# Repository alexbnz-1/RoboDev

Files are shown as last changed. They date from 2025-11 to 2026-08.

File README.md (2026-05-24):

# RoboDev

An open-source STM32-based robotics carrier board with integrated WiFi. Plug in power, plug in your motors and sensors — that's it. No breadboard, no stacked breakout boards, no wiring harness.

> **Status:** Schematic substantially complete · PCB layout not yet started

---

## Architecture

RoboDev uses a two-MCU design:

| | |
|---|---|
| **Primary MCU** | STM32G431RBTx · Cortex-M4F 170 MHz · motor control, real-time I/O |
| **WiFi co-processor** | ESP32-C3-MINI-1-N4 · SPI-connected · handles wireless comms |

---

## What's on the board

| | |
|---|---|
| **DC motors** | 4 channels · DRV8874PWPR · up to ~40 V · ~5 A cont. |
| **Servos** | 16 channels · PCA9685PW · 5 V servo rail |
| **Steppers** | 2× NEMA 17 · TMC2209-LA-T · StealthChop2 · silent operation |
| **CAN bus** | SN65HVD230D · ISO 11898-1 · screw terminal + 5.08 mm connector |
| **IMU** | BMI270 · 6-axis accel + gyro · SPI interface |
| **16-bit ADC** | ADS1115IDGST · 4-channel · I²C |
| **Native ADC** | 3× 2.54 mm headers · STM32 ADC |
| **GPIO expander** | PCF8574DW · 8 additional I/O · I²C |
| **Encoders** | 2 channels · 2.54 mm headers |
| **I²C expansion** | 16 independent ports · mix of QWIIC (JST SH) + 2.54 mm · 2× TCA9548APWR mux |
| **USB** | Type-C · USB4085-GF-A |
| **SWD debug** | 2.54 mm header |
| **UART** | 2× headers (debug + general) |
| **Power input** | XT60PW-M · reverse polarity protection · slide switch |

---

## Motor compatibility

| Motor | Works? | Notes |
|---|---|---|
| TT yellow gearmotors (2WD/4WD) | ✓ | Ideal fit |
| Pololu micro/mini gearmotors | ✓ | Well within limits |
| 25–37 mm DC gearmotors | ✓ | Software current limiting recommended near stall |
| Hobby servos | ✓ | Up to 16 channels via PCA9685 |
| NEMA 17 steppers | ✓ | TMC2209 · 2 A RMS / 2.8 A peak |
| CAN motor controllers (VESC, ODrive) | ✓ | Via SN65HVD230D CAN transceiver |
| 775-size / high-current motors | ✗ | Exceeds DRV8874 — use an external driver |

---

## Power

Five independent rails from a single XT60 input with reverse polarity protection (IRF4905 P-channel MOSFET) and a slide switch.

```
XT60  →  IRF4905 (reverse protect)  →  slide switch
           ├── VMOT    adj. buck (XL4016)  →  DC motors
           ├── VSTEP   adj. buck (XL4016)  →  steppers
           ├── +5V     LM2596T-5           →  servo rail + USB
           └── +3V3    AP2112K-3.3 LDO     →  STM32 + ESP32-C3 + all logic
```

VMOT and VSTEP are separate adjustable bucks so DC motors and steppers can run at different voltages simultaneously.

---

## I²C expansion

16 independent I²C ports behind two TCA9548APWR mux ICs — at zero GPIO cost, sharing the existing I²C bus. Each port is an isolated bus segment, so you can connect multiple devices with the same address across different ports without conflict.

3 ports are QWIIC (JST SH), the rest are standard 2.54 mm 4-pin headers. All carry GND / 3.3V / SDA / SCL.

---

## I²C address map

| Address | Device |
|---|---|
| 0x20 | PCF8574DW — digital GPIO expander |
| 0x3C | OLED display (user-supplied, optional) |
| 0x40 | PCA9685PW — 16-channel servo PWM |
| 0x48 | ADS1115IDGST — 16-bit ADC |
| 0x70 | TCA9548A Mux #1 — expansion ports 0–7 |
| 0x71 | TCA9548A Mux #2 — expansion ports 8–15 |

> BMI270 IMU is on SPI (via ESP32-C3), not I²C.

---

## Schematic structure

The KiCad project uses a hierarchical multi-sheet design:

| Sheet | Contents |
|---|---|
| Root | Top-level interconnect, mounting holes |
| `power` | XT60 input, reverse protect, all buck converters, LDO |
| `stm32` | STM32G431RBTx, SN65HVD230D CAN, USB-C, SWD, UART, ADC headers, encoders |
| `spi_bus` | ESP32-C3-MINI-1-N4 WiFi module, BMI270 IMU, 74HC595 shift register |
| `i2c_bus` | TCA9548A ×2 muxes, ADS1115 ADC, PCF8574 GPIO expander, all I²C headers |
| `motor_dc` | DRV8874PWPR ×4, motor output terminals, fault LEDs |
| `motor_stepper` | TMC2209-LA-T ×2, stepper output terminals, UART config |
| `motor_servo` | PCA9685PW, 16-channel servo headers |

---

## Project status

- [x] Design spec complete
- [x] KiCad schematic — substantially complete (all major blocks drawn)
- [ ] PCB layout
- [ ] Bringup firmware (I²C scan, PWM test, CAN loopback, UART echo)
- [ ] TCA9548A reverse-ARP HAL
- [ ] BMI270 driver + sensor fusion
- [ ] TMC2209 UART config
- [ ] Full LCSC/Mouser BOM with pricing

---

## Bill of materials

Key ICs: STM32G431RBTx · ESP32-C3-MINI-1-N4 · DRV8874PWPR ×4 · TMC2209-LA-T ×2 · PCA9685PW · ADS1115IDGST · PCF8574DW · TCA9548APWR ×2 · SN65HVD230D · BMI270 · USB4085-GF-A · XL4016 ×2 · LM2596T-5 · AP2112K-3.3

---

## Repo structure

```
/
├── hardware/
│   └── Robodev/     KiCad project (schematic + PCB)
├── firmware/        ESP-IDF / STM32 firmware (not yet started)
├── docs/
│   ├── Datasheets/  Component datasheets
│   └── RoboDevDesignSpec.docx
└── README.md
```

---

## Contributing

This is an early-stage open hardware project — no PCB has been fabricated yet. If you want to follow along or contribute, the most useful things right now are:

- KiCad schematic review
- Firmware: STM32 HAL bringup, TCA9548A I²C mux driver, TMC2209 UART configuration
- ESP32-C3 SPI bridge firmware
- BMI270 SPI driver + Madgwick/Mahony filter

---

*STM32 + ESP32-C3 Integrated Robotics Carrier Board · May 2026*

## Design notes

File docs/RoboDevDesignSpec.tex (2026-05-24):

% RoboDev Design Specification
% STM32G431 + ESP32-C3 Integrated Robotics Prototyping Board

\documentclass[11pt,a4paper]{article}

% ── Encoding & fonts ─────────────────────────────────────────────────────────
\usepackage[T1]{fontenc}
\usepackage[utf8]{inputenc}
\usepackage{lmodern}
\usepackage{microtype}

% ── Page layout ──────────────────────────────────────────────────────────────
\usepackage[a4paper, top=25mm, bottom=25mm, left=25mm, right=25mm]{geometry}

% ── Tables ───────────────────────────────────────────────────────────────────
\usepackage{booktabs}
\usepackage{array}
\usepackage{longtable}
\usepackage{tabularx}
\usepackage{multirow}

% ── Colour & graphics ────────────────────────────────────────────────────────
\usepackage[table]{xcolor}
\definecolor{newrow}{RGB}{214,234,248}   % light blue — new in v0.8
\definecolor{warnbg}{RGB}{255,243,205}  % amber — warning boxes
\definecolor{infobg}{RGB}{232,245,233}  % green — info boxes
\definecolor{headergray}{RGB}{52,73,94} % dark header
\definecolor{rowalt}{RGB}{242,242,242}  % alternating row grey

% ── Headings & lists ─────────────────────────────────────────────────────────
\usepackage{titlesec}
\usepackage{enumitem}
\setlist[itemize]{noitemsep, topsep=3pt}

% ── Hyperlinks ───────────────────────────────────────────────────────────────
\usepackage[colorlinks=true, linkcolor=blue!60!black, urlcolor=blue!60!black,
            pdftitle={RoboDev Design Specification v0.8},
            pdfauthor={RoboDev Project}]{hyperref}

% ── Header / footer ──────────────────────────────────────────────────────────
\usepackage{fancyhdr}
\pagestyle{fancy}
\fancyhf{}
\renewcommand{\headrulewidth}{0.4pt}
\fancyhead[L]{\small\textbf{RoboDev} — Design Specification}
\fancyhead[R]{\small v0.8 · May 2026}
\fancyfoot[C]{\small\thepage}

% ── Custom environments ───────────────────────────────────────────────────────
\usepackage{mdframed}
\newmdenv[backgroundcolor=warnbg, linecolor=orange!70!black,
          linewidth=0.8pt, innerleftmargin=8pt, innerrightmargin=8pt,
          innertopmargin=4pt, innerbottommargin=4pt]{warningbox}
\newmdenv[backgroundcolor=infobg, linecolor=green!60!black,
          linewidth=0.8pt, innerleftmargin=8pt, innerrightmargin=8pt,
          innertopmargin=4pt, innerbottommargin=4pt]{infobox}

% ── Misc ─────────────────────────────────────────────────────────────────────
\usepackage{parskip}
\usepackage{textcomp}
\usepackage{siunitx}
\usepackage{amsmath}
\usepackage{amssymb}    % $\checkmark$

% ─────────────────────────────────────────────────────────────────────────────

\begin{document}

% ── Title page ───────────────────────────────────────────────────────────────
\begin{titlepage}
  \centering
  \vspace*{2cm}
  {\Huge\bfseries RoboDev\par}
  \vspace{0.5cm}
  {\large STM32G431 + ESP32-C3 Integrated Robotics Prototyping Board\par}
  \vspace{0.3cm}
  {\normalsize Design Specification $\mid$ v0.8 $\mid$ May 2026\par}
  \vspace{2cm}
  \noindent\rule{\textwidth}{0.4pt}
  \vspace{0.5cm}

  \begin{tabular}{ll}
    \textbf{Status}  & Schematic substantially complete — PCB layout not yet started \\
    \textbf{MCU}     & STM32G431RBTx (primary) + ESP32-C3-MINI-1-N4 (WiFi co-processor) \\
    \textbf{Repo}    & \url{https://github.com/alexbnz-1/RoboDev} \\
  \end{tabular}
  \vspace{0.5cm}
  \noindent\rule{\textwidth}{0.4pt}
\end{titlepage}

% ── Table of contents ─────────────────────────────────────────────────────────
\tableofcontents
\clearpage

% ─────────────────────────────────────────────────────────────────────────────
\section*{Revision History}
\addcontentsline{toc}{section}{Revision History}

\rowcolors{2}{rowalt}{white}
\begin{longtable}{p{1.3cm} p{2cm} p{11cm}}
  \toprule
  \rowcolor{headergray}\color{white}\textbf{Version} &
  \color{white}\textbf{Date} &
  \color{white}\textbf{Summary of Changes} \\
  \midrule\endhead
  v0.1 & Mar 2026 & Initial document from notebook notes (22 Oct -- 17 Nov 2025). \\
  v0.2 & Mar 2026 & DRV8245-Q1 \textrightarrow{} DRV8874. MPU-6050 \textrightarrow{} BMI270. \\
  v0.3 & Mar 2026 & Soldered WROOM module \textrightarrow{} ESP32-S3 DevKitC-1 v1.1 in dual-row headers. \\
  v0.4 & Mar 2026 & NEMA\,17 stepper support: 2$\times$ TMC2209, GPIO26--31 allocated. \\
  v0.5 & Mar 2026 & MPU-6050 GY-521 replaces BMI270. ADS1115, PCF8574, OLED header. Servos 8\textrightarrow{}16. SPI/UART/carrier USB-C removed. 5$\times$ ADC1 headers. \\
  v0.6 & Mar 2026 & CAN bus (TWAI, GPIO7/32, SN65HVD230). Encoders 4\textrightarrow{}2. nFAULT\textrightarrow{}indicator LED. UART1 header (GPIO47/21). GPIO38/48 written off. Separate Vmot-DC and Vstep rails. 0 spare GPIOs. BOM \textasciitilde{}NZ\$82.81. \\
  v0.7 & Mar 2026 & \textbf{$\star$\ I$^2$C expansion array:} 2$\times$ TCA9548A mux (0x70/0x71) + 6$\times$ Qwiic JST\,SH + 10$\times$ 2.54\,mm 4-pin headers = 16 independent expansion ports. Reverse-ARP HAL for automatic peripheral discovery. BOM \textasciitilde{}NZ\$90--92. \\
  \rowcolor{newrow}
  v0.8 & May 2026 & \textbf{$\star$\ Dual-MCU architecture:} STM32G431RBTx replaces ESP32-S3 as primary MCU. ESP32-C3-MINI-1-N4 added as SPI-attached WiFi/BT co-processor. BMI270 IMU moves to SPI (co-processor sheet). USB4085-GF-A Type-C on carrier. SWD debug port added. XT60PW-M replaces XT30 power connector. IRF4905 PMOS reverse protection. 74HC595 shift register added. XL4016 $\times$2 for VMOT + VSTEP. KiCad schematic implementation begun (all major blocks drawn). \\
  \bottomrule
\end{longtable}

% ─────────────────────────────────────────────────────────────────────────────
\section{Introduction}

RoboDev is an open-source integrated robotics prototyping board built around a \textbf{dual-MCU architecture}: an STMicroelectronics STM32G431RBTx Cortex-M4F as the primary motor control processor, and an Espressif ESP32-C3-MINI-1-N4 module as a SPI-attached WiFi and Bluetooth co-processor. It is designed to eliminate the wiring overhead that typically accompanies microcontroller-based robotics projects by integrating motor drivers, a servo PWM controller, stepper motor drivers, a CAN bus transceiver, an IMU, analogue ADC expanders, digital GPIO expansion, an I$^2$C expansion array, and a complete multi-rail power supply onto a single carrier PCB.

The core philosophy of RoboDev is that only three types of wire should ever need to be connected to the board: power in, and wires out to sensors and actuators. All signal routing --- from the MCU to driver ICs, from the I$^2$C bus to peripherals, from the power switch to every rail --- is handled on the PCB itself.

\subsection{Motivation}

Robotics prototyping typically requires a breadboard or custom wiring harness to connect motor driver breakout boards, servo controllers, and sensor modules. This introduces noise susceptibility, mechanical fragility, and significant bring-up time before any firmware can be tested. RoboDev solves this by providing a production-ready carrier board with the STM32G431RBTx at the centre --- a Cortex-M4F processor from ST's G4 series that is purpose-built for motor control and digital power conversion, with hardware PWM timers, FDCAN, and a hardware FPU.

Wireless connectivity is provided by the ESP32-C3-MINI-1-N4, mounted on the carrier and connected to the STM32 via SPI. This separation of concerns keeps the hard-real-time motor control tasks on the deterministic STM32 while offloading WiFi, Bluetooth, and any cloud connectivity tasks to the ESP32-C3.

\subsection{Design Philosophy}

\begin{itemize}
  \item Full-featured and self-contained --- no daughterboards or breakout modules required
  \item Dual-MCU architecture: STM32G431RBTx for real-time control; ESP32-C3-MINI-1-N4 for wireless
  \item Any motor type supported simultaneously: 4$\times$ brushed DC, 16$\times$ servo, 2$\times$ NEMA\,17 stepper, and CAN-capable motor controllers
  \item BMI270 6-axis IMU on SPI for high-speed attitude estimation
  \item Three independently adjustable power rails for motors, steppers, and servos
  \item 16-port I$^2$C expansion array via 2$\times$ TCA9548A mux (zero GPIO cost)
  \item All components hand-solderable --- no BGA or ultra-fine-pitch packages
  \item Open source: schematics, PCB layout, firmware, and documentation on GitHub
\end{itemize}

\subsection{Target Applications}

\begin{itemize}
  \item 2WD and 4WD wheeled robot platforms
  \item Multi-axis robot arms with CAN-capable joint controllers
  \item Mechatronics rigs requiring mixed motor types on a single controller
  \item Autonomous vehicles with wireless telemetry and IMU sensor fusion
  \item Sensor-dense robots using the I$^2$C expansion array for multiple sensors
  \item Educational robotics platforms requiring a robust, well-documented base board
\end{itemize}

% ─────────────────────────────────────────────────────────────────────────────
\section{System Overview}

RoboDev uses a two-MCU design. The \textbf{STM32G431RBTx} is the primary processor, handling all real-time motor control, CAN communication, sensor interfacing, and I$^2$C bus management. The \textbf{ESP32-C3-MINI-1-N4} sits alongside it on the carrier PCB, connected to the STM32 via SPI, and handles all WiFi and Bluetooth tasks.

The board is divided into eight functional domains: power management, primary MCU (STM32), WiFi co-processor (ESP32-C3), motor control (DC, stepper, servo), communication (I$^2$C, CAN, UART), sensing (IMU, analogue, digital), expansion (Qwiic, GPIO headers), and the I$^2$C expansion array.

\subsection{Core Requirements Summary}

\rowcolors{2}{rowalt}{white}
\begin{longtable}{p{4.5cm} p{10cm}}
  \toprule
  \rowcolor{headergray}\color{white}\textbf{Category} & \color{white}\textbf{Requirement / Specification} \\
  \midrule\endhead
  Primary MCU & STM32G431RBTx $\cdot$ Cortex-M4F $\cdot$ 170\,MHz $\cdot$ FPU $\cdot$ 128\,KB Flash $\cdot$ LQFP-64 \\
  WiFi Co-processor & ESP32-C3-MINI-1-N4 $\cdot$ SPI-connected $\cdot$ 802.11b/g/n + Bluetooth 5 \\
  DC Motors & 4 channels $\cdot$ DRV8874PWPR $\cdot$ 4.5--37\,V $\cdot$ 2.1\,A cont.\,/ 6\,A peak $\cdot$ nFAULT LED \\
  Servos & 16 channels $\cdot$ PCA9685PW I$^2$C PWM driver (0x40) $\cdot$ 12-bit resolution $\cdot$ 5\,V servo rail \\
  Stepper Motors & 2 channels $\cdot$ TMC2209-LA-T $\cdot$ NEMA\,17 $\cdot$ 2\,A\,RMS / 2.8\,A peak $\cdot$ UART-configurable $\cdot$ StealthChop2 \\
  CAN Bus & FDCAN (ISO\,11898-1) $\cdot$ SN65HVD230D 3.3\,V transceiver $\cdot$ up to 1\,Mbps $\cdot$ 5.08\,mm screw terminal \\
  IMU & BMI270 $\cdot$ 6-axis accel + gyro $\cdot$ SPI interface $\cdot$ on co-processor sheet \\
  Quadrature Encoders & 2 channels $\cdot$ 4-pin 2.54\,mm headers \\
  Native Analogue ADC & 3$\times$ 2.54\,mm headers $\cdot$ STM32 ADC inputs \\
  I$^2$C Analogue ADC & 4 channels $\cdot$ ADS1115IDGST (0x48) $\cdot$ 16-bit $\cdot$ I$^2$C \\
  GPIO Expander & PCF8574DW (0x20) $\cdot$ 8-channel digital I/O $\cdot$ I$^2$C \\
  I$^2$C Expansion Array & 16 independent ports $\cdot$ 2$\times$ TCA9548APWR mux (0x70/0x71) $\cdot$ 3$\times$ Qwiic + 13$\times$ 2.54\,mm $\cdot$ zero GPIO cost \\
  USB & Type-C $\cdot$ USB4085-GF-A $\cdot$ on STM32 sheet \\
  SWD Debug & 2.54\,mm header $\cdot$ STM32 programming and debug \\
  UART Headers & 2$\times$ 2.54\,mm (debug + general purpose) \\
  Shift Register & 74HC595 $\cdot$ 8-bit serial-in parallel-out $\cdot$ SPI-driven (ESP32-C3 sheet) \\
  Power Input & XT60PW-M $\cdot$ reverse polarity protection (IRF4905 PMOS) $\cdot$ slide switch \\
  \bottomrule
\end{longtable}

% ─────────────────────────────────────────────────────────────────────────────
\section{Power Architecture}

The power system is designed around four independent rails, each serving a distinct subsystem. Separating VMOT from VSTEP allows brushed DC motors and stepper motors to be run at different voltages simultaneously. All rails are derived from a single protected XT60 input, switched by a common high-current slide switch.

\subsection{Power Input and Protection}

Power enters the board via an XT60PW-M connector. Input voltage should be at least 6\,V to allow headroom for the buck converter generating the 5\,V logic rail. Do not exceed 36\,V (the rated ceiling of the XL4016 buck converters).

An IRF4905 P-channel power MOSFET provides reverse voltage protection on VIN before the power switch. MBR2045CT Schottky diodes are used for power path management. An SS14 diode handles USB/power path arbitration.

\begin{warningbox}
\textbf{Warning:} A high-current slide switch (OS102011MS2QN1) is placed after the reverse voltage protection circuit. It switches all rails simultaneously. When laying out the PCB, ensure the switch trace width is adequate for the total system current.
\end{warningbox}

\subsection{Power Rails}

\rowcolors{2}{rowalt}{white}
\begin{longtable}{p{2cm} p{2.5cm} p{2.2cm} p{3cm} p{4.8cm}}
  \toprule
  \rowcolor{headergray}\color{white}\textbf{Rail} &
  \color{white}\textbf{Output} &
  \color{white}\textbf{Current} &
  \color{white}\textbf{Load} &
  \color{white}\textbf{Key Component / Notes} \\
  \midrule\endhead
  VMOT   & Adj. 4.5--24\,V & 5\,A+ cont. & DC Motors M1--M4     & XL4016 step-down $\cdot$ trimmer pot on FB $\cdot$ 470\,\textmu F bulk $\times$4 \\
  VSTEP  & Adj. 4.5--24\,V & 3\,A+ cont. & Steppers S1--S2      & XL4016 step-down $\cdot$ independent rail \\
  +5\,V  & Fixed 5\,V      & 3\,A+ cont. & Servo rail, USB, ESP32-C3 & LM2596T-5 synchronous buck $\cdot$ 33\,\textmu H inductor \\
  +3.3\,V& Fixed 3.3\,V    & 1\,A+ cont. & STM32, all ICs, sensors & AP2112K-3.3 LDO from 5\,V $\cdot$ all I$^2$C devices \\
  \bottomrule
\end{longtable}

\begin{warningbox}
\textbf{Warning:} VMOT and VSTEP are independent adjustable XL4016 buck converters. Each has its own trimmer potentiometer. Label both clearly on the PCB silkscreen to prevent accidental cross-connection.
\end{warningbox}

\subsection{Bulk Decoupling Capacitors}

Each DRV8874 DC motor driver requires at least one electrolytic bulk capacitor rated for the VMOT voltage placed as close as possible to the VM pin. A minimum of 470\,\textmu F at 50\,V is specified per driver. Each TMC2209 stepper driver similarly requires bulk capacitance on the VSTEP rail. All ICs additionally receive 100\,nF ceramic decoupling capacitors.

% ─────────────────────────────────────────────────────────────────────────────
\section{Microcontrollers}

\subsection{Primary MCU --- STM32G431RBTx}

The STM32G431RBTx (U\_MCU1) is a 64-pin LQFP Cortex-M4F microcontroller from STMicroelectronics' G4 series. Running at 170\,MHz with a hardware FPU, it is purpose-built for motor control and digital power conversion applications.

\begin{warningbox}
\textbf{Note:} The schematic sheet is labelled \texttt{stm32} and uses file \texttt{esp32.kicad\_sch} — a legacy filename from the earlier ESP32-S3 design. The actual placed component is STM32G431RBTx.
\end{warningbox}

Key peripherals used on this board:

\begin{itemize}
  \item \textbf{Timers (TIM/HRTIM)} --- motor PWM generation for M1--M4 DC motor channels and S1--S2 stepper STEP pulses
  \item \textbf{FDCAN} --- hardware CAN controller via SN65HVD230D transceiver
  \item \textbf{I$^2$C} --- shared bus for PCA9685, ADS1115, PCF8574, TCA9548A $\times$2
  \item \textbf{SPI} --- connection to ESP32-C3-MINI-1-N4 co-processor and 74HC595 shift register
  \item \textbf{UART/USART} --- TMC2209 UART configuration interface + debug/general UART headers
  \item \textbf{ADC} --- native ADC inputs broken out to 3$\times$ 2.54\,mm headers
  \item \textbf{USB FS} --- via USB4085-GF-A Type-C connector
  \item \textbf{SWD} --- programming and debug via 2.54\,mm header (J\_SWD1)
\end{itemize}

The BOOT0 pin is pulled to GND via a 10\,k$\Omega$ resistor with a MJTP1230 push-button to allow entry into the DFU bootloader. A separate MJTP1230 provides system RESET. A 100\,nF capacitor is placed on the $\overline{\text{NRST}}$ pin.

\subsection{WiFi Co-processor --- ESP32-C3-MINI-1-N4}

The ESP32-C3-MINI-1-N4 (on the \texttt{spi\_bus} sheet) provides 802.11b/g/n WiFi and Bluetooth 5 LE connectivity. It is connected to the STM32 via SPI, with the following interface signals:

\begin{itemize}
  \item \textbf{SPI\_SCK, SPI\_MOSI, SPI\_MISO} --- SPI bus to/from STM32
  \item \textbf{SPI\_CS} --- chip select from STM32
  \item \textbf{SPI\_LATCH} --- latch signal (also drives 74HC595 shift register)
  \item \textbf{WIFI\_IRQ} --- interrupt output from ESP32-C3 to STM32
\end{itemize}

The ESP32-C3 also connects to the BMI270 IMU and the 74HC595 shift register on its sheet.

\subsection{74HC595 Shift Register}

A 74HC595 8-bit serial-in parallel-out shift register is placed on the \texttt{spi\_bus} sheet alongside the ESP32-C3. It is clocked via the SPI bus (or the SPI\_LATCH signal), providing 8 additional digital output lines without consuming extra GPIO on the STM32. Typical use cases include status LEDs, output expansion, and simple digital control signals.

% ─────────────────────────────────────────────────────────────────────────────
\section{Signal Interface Summary}

The following table lists the hierarchical sheet pin names that cross between sheets in the KiCad schematic. Exact STM32 pin numbers are TBD (to be verified during PCB layout).

\rowcolors{2}{rowalt}{white}
\begin{longtable}{p{3.5cm} p{2cm} p{3cm} p{6cm}}
  \toprule
  \rowcolor{headergray}\color{white}\textbf{Signal} &
  \color{white}\textbf{Dir.} &
  \color{white}\textbf{Sheet} &
  \color{white}\textbf{Function} \\
  \midrule\endhead
  M1\_PWM / M1\_DIR & Out & stm32 \textrightarrow{} motor\_dc & DC motor M1 PWM + direction \\
  M2\_PWM / M2\_DIR & Out & stm32 \textrightarrow{} motor\_dc & DC motor M2 PWM + direction \\
  M3\_PWM / M3\_DIR & Out & stm32 \textrightarrow{} motor\_dc & DC motor M3 PWM + direction \\
  M4\_PWM / M4\_DIR & Out & stm32 \textrightarrow{} motor\_dc & DC motor M4 PWM + direction \\
  S1\_STEP/DIR/EN   & Out & stm32 \textrightarrow{} motor\_stepper & Stepper S1 control \\
  S2\_STEP/DIR/EN   & Out & stm32 \textrightarrow{} motor\_stepper & Stepper S2 control \\
  TMC\_UART\_TX/RX  & Bidir & stm32 $\leftrightarrow$ motor\_stepper & TMC2209 UART config bus \\
  I2C\_SCL/SDA      & Out & stm32 \textrightarrow{} i2c\_bus, motor\_servo & Shared I$^2$C bus \\
  SPI\_CS/MOSI/MISO/SCK & Bidir & stm32 $\leftrightarrow$ spi\_bus & SPI to ESP32-C3 + 74HC595 \\
  SPI\_LATCH        & Out & stm32 \textrightarrow{} spi\_bus & 74HC595 latch \\
  WIFI\_IRQ         & In  & spi\_bus \textrightarrow{} stm32 & ESP32-C3 interrupt \\
  IMU\_INT1         & In  & spi\_bus \textrightarrow{} stm32 & BMI270 interrupt \\
  GPIO\_INT         & In  & i2c\_bus \textrightarrow{} stm32 & PCF8574 interrupt \\
  IPROPI\_M1--M4    & In  & motor\_dc \textrightarrow{} i2c\_bus & DRV8874 current sense to ADS1115 \\
  VMOT              & Pwr & power \textrightarrow{} motor\_dc & DC motor power rail \\
  VSTEP             & Pwr & power \textrightarrow{} motor\_stepper & Stepper power rail \\
  VSERVO            & Pwr & power \textrightarrow{} motor\_servo & Servo power rail \\
  VBUS / ADC\_VIN   & Pwr & power \textrightarrow{} stm32 & USB bus power + ADC reference \\
  \bottomrule
\end{longtable}

% ─────────────────────────────────────────────────────────────────────────────
\section{Motor Control}

\subsection{DC Brushed Motors --- DRV8874PWPR \texorpdfstring{$\times$}{x} 4}

Four DRV8874PWPR H-bridge motor driver ICs (U\_M1--U\_M4) provide control for four independent brushed DC motor channels (M1--M4). The DRV8874 is a fully integrated H-bridge with hardware overcurrent protection, thermal shutdown, and undervoltage lockout.

\rowcolors{2}{rowalt}{white}
\begin{longtable}{p{5cm} p{10cm}}
  \toprule
  \rowcolor{headergray}\color{white}\textbf{Parameter} & \color{white}\textbf{Value / Detail} \\
  \midrule\endhead
  Part number & DRV8874PWPR (HTSSOP-16) \\
  Supply voltage (VM) & 4.5\,V -- 37\,V (VMOT rail) \\
  Continuous current & 2.1\,A per channel \\
  Peak current & 6\,A per channel \\
  Control M1 & M1\_PWM (PWM/Phase), M1\_DIR (DIR/Enable) from STM32 \\
  Control M2 & M2\_PWM, M2\_DIR \\
  Control M3 & M3\_PWM, M3\_DIR \\
  Control M4 & M4\_PWM, M4\_DIR \\
  Output connector & 2-pin 5.08\,mm screw terminal per channel \\
  nFAULT handling & All 4 nFAULT pins wired-OR open-drain \textrightarrow{} red indicator LED (LTST-C190KRKT). No MCU GPIO consumed. \\
  Bulk capacitance & 470\,\textmu F 50\,V electrolytic per driver (C\_VM1--C\_VM4), close to VM pin \\
  Current sense & IPROPI output routed to ADS1115 (A6--A9) for per-motor current monitoring \\
  \bottomrule
\end{longtable}

\subsection{NEMA 17 Stepper Motors --- TMC2209-LA-T \texorpdfstring{$\times$}{x} 2}

Two TMC2209-LA-T silent stepper motor driver ICs (U\_S1--U\_S2) drive two NEMA\,17 bipolar stepper motors from the independent VSTEP rail. The TMC2209 features StealthChop2 for near-silent operation and SpreadCycle for high-torque applications, configurable via UART.

\rowcolors{2}{rowalt}{white}
\begin{longtable}{p{5cm} p{10cm}}
  \toprule
  \rowcolor{headergray}\color{white}\textbf{Parameter} & \color{white}\textbf{Value / Detail} \\
  \midrule\endhead
  Part number & TMC2209-LA-T (QFN-28) \\
  Supply voltage (VM) & 4.5\,V -- 36\,V (VSTEP rail --- independent from VMOT) \\
  RMS current & 2.0\,A RMS per channel \\
  Peak current & 2.8\,A peak per channel \\
  Control S1 & S1\_STEP, S1\_DIR, S1\_EN (active LOW) \\
  Control S2 & S2\_STEP, S2\_DIR, S2\_EN (active LOW) \\
  EN pull-up & 10\,k$\Omega$ to 3.3\,V --- drivers disabled by default at power-on \\
  UART config & TMC\_UART\_TX/RX to STM32 (optional per-application current tuning) \\
  Bulk capacitance & 100\,\textmu F 35\,V+ per driver \\
  \bottomrule
\end{longtable}

\begin{infobox}
\textbf{Note:} The VSTEP rail is intentionally separate from VMOT. This allows, for example, 12\,V NEMA\,17 operation alongside 6\,V DC gearmotors simultaneously.
\end{infobox}

\subsection{Servo Motors --- PCA9685PW \texorpdfstring{$\times$}{x} 16}

A PCA9685PW 16-channel 12-bit PWM driver IC provides servo control for up to 16 hobby servo channels simultaneously via I$^2$C. All 16 PWM outputs are broken out to 3-pin 2.54\,mm servo headers carrying GND, VSERVO, and PWM signal.

\rowcolors{2}{rowalt}{white}
\begin{longtable}{p{5cm} p{10cm}}
  \toprule
  \rowcolor{headergray}\color{white}\textbf{Parameter} & \color{white}\textbf{Value / Detail} \\
  \midrule\endhead
  Part number & PCA9685PW (TSSOP-28) \\
  I$^2$C address & 0x40 (ADDR pins \textrightarrow{} GND) \\
  PWM resolution & 12-bit (4096 steps) \\
  PWM frequency & Configurable 24\,Hz -- 1526\,Hz (typically 50\,Hz for standard servos) \\
  Servo voltage & VSERVO (derived from +5\,V rail via MBR2045CT protection diode) \\
  Servo headers & 3-pin 2.54\,mm GND / VSERVO / PWM (16 channels) \\
  Control interface & I$^2$C via STM32 I$^2$C bus \\
  \bottomrule
\end{longtable}

\subsection{Motor Compatibility}

\rowcolors{2}{rowalt}{white}
\begin{longtable}{p{6cm} p{2cm} p{7cm}}
  \toprule
  \rowcolor{headergray}\color{white}\textbf{Motor Type} &
  \color{white}\textbf{Compatible?} &
  \color{white}\textbf{Notes} \\
  \midrule\endhead
  TT yellow gearmotors (2WD/4WD) & $\checkmark$ & Common chassis motors --- ideal fit \\
  Pololu micro/mini DC gearmotors & $\checkmark$ & Well within DRV8874 2.1\,A continuous rating \\
  25\,mm / 37\,mm DC gearmotors   & $\checkmark$* & Stall may approach 6\,A peak --- current limiting recommended \\
  775-size DC motors               & $\times$  & Exceeds DRV8874 continuous rating --- use external driver \\
  Hobby servos (3--8.4\,V)         & $\checkmark$ & PCA9685 servo rail, up to 16 channels simultaneously \\
  NEMA\,17 stepper motors          & $\checkmark$ & TMC2209 StealthChop2 $\cdot$ up to 2\,A RMS / 2.8\,A peak \\
  CAN motor controllers (VESC, ODrive) & $\checkmark$ & FDCAN via SN65HVD230D $\cdot$ ISO\,11898-1 \\
  \bottomrule
\end{longtable}

% ─────────────────────────────────────────────────────────────────────────────
\section{Communication Interfaces}

\subsection{\texorpdfstring{I$^2$C}{I2C} Bus}

A single I$^2$C bus from the STM32 carries all on-board I$^2$C peripherals plus the TCA9548A expansion array. Pull-up resistors of 4.7\,k$\Omega$ to 3.3\,V are provided on-board.

\rowcolors{2}{rowalt}{white}
\begin{longtable}{p{3cm} p{1.5cm} p{4cm} p{6cm}}
  \toprule
  \rowcolor{headergray}\color{white}\textbf{Device} &
  \color{white}\textbf{Addr.} &
  \color{white}\textbf{Function} &
  \color{white}\textbf{Notes} \\
  \midrule\endhead
  PCA9685PW         & 0x40 & 16-ch servo PWM driver   & Main bus --- always visible \\
  ADS1115IDGST      & 0x48 & 4-ch 16-bit ADC          & Main bus --- ADDR\textrightarrow{}GND \\
  PCF8574DW         & 0x20 & 8-ch digital GPIO expander & Main bus --- INT to STM32 (GPIO\_INT) \\
  OLED display      & 0x3C & 0.96\,'' display (user-supplied) & 4-pin 2.54\,mm header (J\_OLED1) \\
  TCA9548APWR Mux\,\#1 & 0x70 & I$^2$C mux --- ports 0--7 & Main bus --- always visible \\
  TCA9548APWR Mux\,\#2 & 0x71 & I$^2$C mux --- ports 8--15 & Main bus --- always visible \\
  Expansion 0--15   & Any  & User I$^2$C devices       & Behind mux --- no address conflicts \\
  \bottomrule
\end{longtable}

\begin{infobox}
\textbf{Note:} The BMI270 IMU is on \textbf{SPI}, not I$^2$C. It is located on the \texttt{spi\_bus} sheet alongside the ESP32-C3. The main I$^2$C bus has seven on-board devices; no address conflicts exist between them.
\end{infobox}

\subsection{CAN Bus (FDCAN)}

CAN bus support is implemented using the STM32G431's built-in FDCAN controller, conforming to ISO\,11898-1. An SN65HVD230D 3.3\,V CAN transceiver provides the physical layer.

\rowcolors{2}{rowalt}{white}
\begin{longtable}{p{4cm} p{11cm}}
  \toprule
  \rowcolor{headergray}\color{white}\textbf{Parameter} & \color{white}\textbf{Value / Detail} \\
  \midrule\endhead
  Protocol & ISO\,11898-1 (CAN 2.0A/B / CAN FD capable) via STM32 FDCAN hardware \\
  Transceiver & SN65HVD230D (SOIC-8, 3.3\,V compatible, up to 1\,Mbps) \\
  Bus connector & 5.08\,mm 2-pin screw terminal (J\_CAN1) --- CANH / CANL \\
  Termination & 120\,$\Omega$ resistor (R\_CAN\_TERM1) on board \\
  Logic level & 3.3\,V --- directly compatible with STM32G431 GPIO \\
  Use cases & CAN motor controllers (VESC, ODrive), robot arm joints, inter-board comms \\
  \bottomrule
\end{longtable}

\begin{warningbox}
\textbf{Warning:} Do not substitute the SN65HVD230D with a 5\,V transceiver such as the MCP2551. The STM32G431 GPIO pins are 3.3\,V tolerant; a 5\,V transceiver output will permanently damage the MCU.
\end{warningbox}

\subsection{USB (Type-C)}

A USB4085-GF-A USB Type-C connector (X1) on the STM32 sheet provides USB Full-Speed connectivity directly to the STM32G431's USB FS peripheral. This is used for firmware programming (DFU bootloader via BOOT0 button) and virtual COM port (VCP) communication.

\subsection{SWD Debug Interface}

A 4-pin 2.54\,mm SWD header (J\_SWD1) exposes the STM32G431's Serial Wire Debug interface (SWDIO / SWDCLK / GND / 3.3\,V). This supports programming and live debugging via ST-LINK, J-Link, or compatible probe.

\subsection{UART Headers}

\begin{itemize}
  \item \textbf{J\_UART\_DBG1} --- UART debug port (4-pin 2.54\,mm). Intended for serial monitor and low-level firmware diagnostics.
  \item \textbf{J\_UART2} --- General-purpose UART header (4-pin 2.54\,mm). Use for GPS (NMEA), LiDAR (RPLIDAR, TF-Luna), or any UART-based peripheral.
\end{itemize}

% ─────────────────────────────────────────────────────────────────────────────
\section{Sensing and Analogue Inputs}

\subsection{Inertial Measurement Unit --- BMI270}

The BMI270 6-axis IMU is placed on the \texttt{spi\_bus} sheet alongside the ESP32-C3-MINI-1-N4. It provides 3-axis accelerometer and 3-axis gyroscope data via SPI. An interrupt output (IMU\_INT1) is routed to the STM32 for data-ready notification.

\begin{itemize}
  \item Interface: SPI
  \item Interrupt: IMU\_INT1 \textrightarrow{} STM32
  \item Firmware: BMI270 SPI driver recommended; Madgwick or Mahony filter for attitude estimation
\end{itemize}

\subsection{Native Analogue Inputs --- ADC Headers}

Three 2.54\,mm headers (J\_ADC1, J\_ADC2, J\_ADC3) break out STM32G431 ADC input channels. Exact GPIO assignments are to be determined during schematic finalisation and PCB layout.

\begin{itemize}
  \item Pinout: GND / 3.3\,V / SIG (3-pin headers)
  \item Resolution: 12-bit (STM32 ADC1/ADC2)
\end{itemize}

\subsection{\texorpdfstring{I$^2$C}{I2C} Analogue Inputs --- ADS1115IDGST}

The ADS1115IDGST 16-bit I$^2$C ADC (U\_ADC1) provides four additional analogue channels (A6--A9) at significantly higher resolution than the native ADC. The DRV8874 IPROPI current sense outputs are routed here for per-motor current monitoring.

\begin{itemize}
  \item I$^2$C address: 0x48 (ADDR\textrightarrow{}GND)
  \item Resolution: 16-bit ($\pm$32767 counts), programmable gain: $\pm$0.256\,V to $\pm$6.144\,V FSR
  \item IPROPI inputs: IPROPI\_M1--M4 from DRV8874 \textrightarrow{} ADS1115 (via i2c\_bus sheet)
\end{itemize}

\subsection{PCF8574DW --- Digital GPIO Expander}

The PCF8574DW (U\_GPIO1) provides 8 additional digital I/O lines via I$^2$C at address 0x20. An INT signal is routed to the STM32 (GPIO\_INT) for interrupt-driven pin change notification. A pull-up resistor (R\_GPIO\_INT1) is placed on the INT line.

\subsection{Quadrature Encoders}

Two quadrature encoder channels are supported. Each channel provides a 4-pin 2.54\,mm header (J\_ENC1, J\_ENC2) with pinout GND / 3.3\,V / Chan-A / Chan-B.

\subsection{GPIO Header}

A general-purpose GPIO header (J\_GPIO1) breaks out additional STM32 GPIO pins for user-defined digital I/O.

% ─────────────────────────────────────────────────────────────────────────────
\section{\texorpdfstring{I$^2$C}{I2C} Expansion Array}

Two TCA9548APWR 8-channel I$^2$C multiplexers (U\_MUX1 at 0x70, U\_MUX2 at 0x71) are added to the main I$^2$C bus. Each provides 8 independently switched downstream channels, giving 16 expansion ports total. Each port is a fully isolated I$^2$C segment --- devices on different ports can share the same I$^2$C address without conflict.

\subsection{Expansion Port Layout}

\rowcolors{2}{rowalt}{white}
\begin{longtable}{p{1.2cm} p{3.5cm} p{3.5cm} p{2.5cm} p{4cm}}
  \toprule
  \rowcolor{headergray}\color{white}\textbf{Port} &
  \color{white}\textbf{Connector} &
  \color{white}\textbf{Mux Channel} &
  \color{white}\textbf{Isolation} &
  \color{white}\textbf{Notes} \\
  \midrule\endhead
  0  & QWIIC JST\,SH 4-pin & TCA9548A \#1 Ch0 & Independent & QWIIC port 1 on Mux\,\#1 \\
  1  & QWIIC JST\,SH 4-pin & TCA9548A \#1 Ch1 & Independent & QWIIC port 2 on Mux\,\#1 \\
  2  & QWIIC JST\,SH 4-pin & TCA9548A \#1 Ch2 & Independent & QWIIC port 3 on Mux\,\#1 \\
  3  & 2.54\,mm 4-pin      & TCA9548A \#1 Ch3 & Independent & GND/3.3\,V/SDA/SCL \\
  4  & 2.54\,mm 4-pin      & TCA9548A \#1 Ch4 & Independent & \\
  5  & 2.54\,mm 4-pin      & TCA9548A \#1 Ch5 & Independent & \\
  6  & 2.54\,mm 4-pin      & TCA9548A \#1 Ch6 & Independent & \\
  7  & 2.54\,mm 4-pin      & TCA9548A \#1 Ch7 & Independent & \\
  8  & QWIIC JST\,SH 4-pin & TCA9548A \#2 Ch0 & Independent & QWIIC port 1 on Mux\,\#2 \\
  9  & 2.54\,mm 4-pin      & TCA9548A \#2 Ch1 & Independent & \\
  10 & 2.54\,mm 4-pin      & TCA9548A \#2 Ch2 & Independent & \\
  11 & 2.54\,mm 4-pin      & TCA9548A \#2 Ch3 & Independent & \\
  12 & 2.54\,mm 4-pin      & TCA9548A \#2 Ch4 & Independent & \\
  13 & 2.54\,mm 4-pin      & TCA9548A \#2 Ch5 & Independent & \\
  14 & 2.54\,mm 4-pin      & TCA9548A \#2 Ch6 & Independent & \\
  15 & 2.54\,mm 4-pin      & TCA9548A \#2 Ch7 & Independent & \\
  \bottomrule
\end{longtable}

\subsection{TCA9548A Architecture}

\rowcolors{2}{rowalt}{white}
\begin{longtable}{p{5cm} p{10cm}}
  \toprule
  \rowcolor{headergray}\color{white}\textbf{Parameter} & \color{white}\textbf{Value / Detail} \\
  \midrule\endhead
  Part number & TCA9548APWR (TSSOP-24) \\
  I$^2$C address Mux\,\#1 & 0x70 (A2/A1/A0 = 0/0/0 \textrightarrow{} GND) \\
  I$^2$C address Mux\,\#2 & 0x71 (A2/A1/A0 = 0/0/1 \textrightarrow{} Mux\,\#2 A0 \textrightarrow{} 3.3\,V) \\
  Channels per IC & 8 independent I$^2$C downstream channels \\
  Total expansion ports & 16 (8 from Mux\,\#1 + 8 from Mux\,\#2) \\
  Supply voltage & 3.3\,V \\
  Pull-up resistors & 4.7\,k$\Omega$ on SDA/SCL of main bus only (mux outputs are active) \\
  Address conflict risk & None between ports --- each port is on an independently switched segment \\
  Reset pull-ups & 10\,k$\Omega$ pull-ups on /RESET pins of both TCA9548A ICs \\
  \bottomrule
\end{longtable}

\subsection{Reverse-ARP HAL --- Automatic Peripheral Discovery}

The firmware HAL implements a reverse-ARP discovery mechanism for the expansion array. On startup, the HAL iterates through all 16 expansion ports, temporarily enables each channel, performs an I$^2$C scan, records any device addresses found, and then disables the channel. The result is a port map that application code can query.

\begin{itemize}
  \item On startup: scan all 16 ports \textrightarrow{} build port map \textrightarrow{} log device addresses per port
  \item At runtime: request \texttt{i2c\_port\_N} \textrightarrow{} HAL enables TCA9548A channel \textrightarrow{} performs transaction \textrightarrow{} disables channel
  \item No address conflicts possible --- HAL enforces single-channel activation
\end{itemize}

\begin{warningbox}
\textbf{Warning:} Only one TCA9548A channel should be active at any time. The HAL enforces this. Do not manually write to the TCA9548A channel registers from application code while the HAL is active.
\end{warningbox}

% ─────────────────────────────────────────────────────────────────────────────
\section{Connector Reference}

\rowcolors{2}{rowalt}{white}
\begin{longtable}{p{3cm} p{2.5cm} p{1.5cm} p{2.5cm} p{5cm}}
  \toprule
  \rowcolor{headergray}\color{white}\textbf{Ref} &
  \color{white}\textbf{Type} &
  \color{white}\textbf{Qty} &
  \color{white}\textbf{Pitch} &
  \color{white}\textbf{Function / Pinout} \\
  \midrule\endhead
  J\_XT60             & XT60PW-M      & 1  & XT60       & VIN power input \\
  J\_CAN1             & Screw terminal& 1  & 5.08\,mm 2-pin & CAN: CANH / CANL \\
  J\_ENC1, J\_ENC2    & Pin header    & 2  & 2.54\,mm 4-pin & Encoders: GND / 3.3\,V / Chan-A / Chan-B \\
  J\_UART\_DBG1       & Pin header    & 1  & 2.54\,mm 4-pin & UART debug: GND / 3.3\,V / TX / RX \\
  J\_UART2            & Pin header    & 1  & 2.54\,mm 4-pin & UART general: GND / 3.3\,V / TX / RX \\
  J\_OLED1            & Pin header    & 1  & 2.54\,mm 4-pin & OLED: GND / 3.3\,V / SDA / SCL \\
  J\_SWD1             & Pin header    & 1  & 2.54\,mm 4-pin & SWD: GND / 3.3\,V / SWDIO / SWDCLK \\
  J\_ADC1--J\_ADC3    & Pin header    & 3  & 2.54\,mm 3-pin & ADC: GND / 3.3\,V / SIG \\
  J\_GPIO1            & Pin header    & 1  & 2.54\,mm 4-pin & Direct GPIO header \\
  Servo headers       & Pin header    & 16 & 2.54\,mm 3-pin & Servo: GND / VSERVO / PWM \\
  Motor terminals     & Screw terminal& 4  & 5.08\,mm 2-pin & DC motor outputs M1--M4 \\
  Stepper headers     & Pin header    & 2  & 2.54\,mm 4-pin & STEP/DIR/EN per stepper \\
  J\_MUX1\_CH0--CH7  & Mixed         & 8  & QWIIC / 2.54\,mm & I$^2$C expansion ports 0--7 \\
  J\_MUX2\_CH0--CH7  & Mixed         & 8  & QWIIC / 2.54\,mm & I$^2$C expansion ports 8--15 \\
  X1                  & USB Type-C    & 1  & USB4085-GF-A & USB FS / DFU programming \\
  H1--H4              & Mounting hole & 4  & M3 pad       & Grounded M3 mounting holes \\
  \bottomrule
\end{longtable}

% ─────────────────────────────────────────────────────────────────────────────
\section{Bill of Materials (v0.8)}

Estimated mid-range unit pricing at Qty\,=\,1. Excludes PCB assembly labour, shipping, and import duties. Rows highlighted in blue are new or significantly changed in v0.8.

\rowcolors{2}{rowalt}{white}
\begin{longtable}{p{0.5cm} p{4.5cm} p{3.5cm} p{0.8cm} p{5.5cm}}
  \toprule
  \rowcolor{headergray}\color{white}\textbf{\#} &
  \color{white}\textbf{Component} &
  \color{white}\textbf{Part Number} &
  \color{white}\textbf{Qty} &
  \color{white}\textbf{Notes} \\
  \midrule\endhead
  \rowcolor{newrow}1 & STM32G431RBTx MCU & STM32G431RBTx (LQFP-64) & 1 & Primary MCU, 170\,MHz Cortex-M4F \\
  \rowcolor{newrow}2 & ESP32-C3-MINI-1-N4 & ESP32-C3-MINI-1-N4 & 1 & WiFi/BT co-processor, SPI interface \\
  3 & DRV8874 H-Bridge & DRV8874PWPR (HTSSOP-16) & 4 & DC motors M1--M4 \\
  4 & SN65HVD230 CAN & SN65HVD230D (SOIC-8) & 1 & CAN bus transceiver \\
  5 & CAN screw terminal & 5.08\,mm 2-pin & 1 & CANH / CANL \\
  6 & nFAULT LED & LTST-C190KRKT Red & 1 & DRV8874 fault indicator \\
  7 & PCA9685 servo driver & PCA9685PW (TSSOP-28) & 1 & 16-ch PWM servo \\
  8 & ADS1115 ADC & ADS1115IDGST (MSOP-10) & 1 & 16-bit I$^2$C ADC, motor current sense \\
  9 & PCF8574 GPIO expander & PCF8574DW (SOIC-16) & 1 & 8-ch digital I/O expander \\
  10 & TCA9548A I$^2$C Mux & TCA9548APWR (TSSOP-24) & 2 & Mux\,\#1 (0x70), Mux\,\#2 (0x71) \\
  11 & QWIIC header & JST\,SH SM04B-SRSS-TB & 3 & I$^2$C expansion QWIIC ports \\
  12 & Expansion 2.54\,mm headers & 4-pin 2.54\,mm & 13 & I$^2$C expansion headers \\
  \rowcolor{newrow}13 & BMI270 IMU & BMI270 & 1 & 6-axis IMU, SPI interface \\
  \rowcolor{newrow}14 & 74HC595 shift register & 74HC595 & 1 & 8-bit serial output expander \\
  \rowcolor{newrow}15 & USB Type-C connector & USB4085-GF-A & 1 & USB FS / DFU \\
  \rowcolor{newrow}16 & XT60 power connector & XT60PW-M & 1 & Main power input \\
  \rowcolor{newrow}17 & IRF4905 PMOS & IRF4905 & 1 & Reverse polarity protection \\
  18 & MBR2045CT Schottky & MBR2045CT & 1+ & Power path protection \\
  19 & SS14 Schottky diode & SS14 & 1 & USB power path \\
  20 & OS102011MS2QN1 switch & OS102011MS2QN1 & 1 & Main power slide switch \\
  21 & MJTP1230 pushbutton & MJTP1230 & 2 & BOOT0 + RESET buttons \\
  22 & XL4016 buck converter & XL4016 & 2 & VMOT + VSTEP adjustable rails \\
  23 & LM2596T-5 buck & LM2596T-5 & 1 & Fixed 5\,V logic rail \\
  24 & AP2112K-3.3 LDO & AP2112K-3.3 (SOT-25) & 1 & Fixed 3.3\,V logic \\
  25 & 33\,\textmu H / 4\,A inductor & -- & 1 & 5\,V buck output filter \\
  26 & 47\,\textmu H / 12\,A inductor & -- & 2 & VMOT / VSTEP buck output filters \\
  27 & Electrolytic cap 470\,\textmu F 50\,V & -- & 3+ & Motor/bulk capacitors \\
  28 & Electrolytic cap 680\,\textmu F 50\,V & -- & 1 & VIN bulk input cap \\
  29 & Electrolytic cap 220\,\textmu F 25\,V & -- & 1 & 5\,V rail bulk cap \\
  30 & Bourns 3296W trimmer 10\,k$\Omega$ & Bourns 3296W & 2+ & VMOT / VSTEP feedback dividers \\
  31 & 100\,nF ceramic 0603 ($\times$25) & GRM188R71C104 & 25 & IC bypass decoupling \\
  32 & Resistor assortment 0603 ($\times$40) & Misc. & 40 & Pull-ups, dividers, LED limiting \\
  33 & 2-layer PCB \textasciitilde{}130$\times$95\,mm & JLCPCB / PCBWay & 1 & Design TBD \\
  \bottomrule
\end{longtable}

% ─────────────────────────────────────────────────────────────────────────────
\section{Recommended Improvements}

\rowcolors{2}{rowalt}{white}
\begin{longtable}{p{4cm} p{2cm} p{9cm}}
  \toprule
  \rowcolor{headergray}\color{white}\textbf{Improvement} &
  \color{white}\textbf{Priority} &
  \color{white}\textbf{Notes} \\
  \midrule\endhead
  Battery voltage monitor & High & Resistor divider on VIN \textrightarrow{} any ADC header. Zero GPIO cost. \\
  Per-motor IPROPI current sense & High & DRV8874 IPROPI \textrightarrow{} ADS1115. Already routed in schematic (IPROPI\_M1--M4). \\
  LiPo XT60 connector & Medium & XT60PW-M already placed. Consider adding balancer connector header. \\
  On-board buzzer & Low & Requires an available GPIO. Assign from freed signals during layout. \\
  WS2812B RGB status LED & Low & ESP32-C3 has spare GPIOs --- can drive RGB LED without loading STM32. \\
  CAN bus termination option & Medium & 120\,$\Omega$ R\_CAN\_TERM1 already placed. Add solder-bridge jumper to enable/disable. \\
  \bottomrule
\end{longtable}

% ─────────────────────────────────────────────────────────────────────────────
\section{Open Questions and Next Steps}

\subsection{Verification Required}

\begin{itemize}
  \item Confirm all STM32G431RBTx pin assignments in schematic (ESP32-S3 pin table is obsolete)
  \item Prototype I$^2$C bus --- verify all 6 on-board device addresses and pull-up values at full loading
  \item Prototype CAN bus --- verify SN65HVD230D wiring and FDCAN firmware configuration (bitrate, mode)
  \item Verify TCA9548A address selection resistors for 0x70 (all pins\textrightarrow{}GND) and 0x71 (A0\textrightarrow{}3.3\,V)
  \item Test SPI interface between STM32 and ESP32-C3 --- confirm protocol, clock speed, and IRQ behaviour
  \item Confirm BMI270 SPI routing and interrupt (IMU\_INT1) behaviour
\end{itemize}

\subsection{KiCad / PCB Design Tasks}

\begin{itemize}
  \item Review and clean up \texttt{esp32.kicad\_sch} --- rename sheet from ``stm32'' to something less confusing; rename file from \texttt{esp32.kicad\_sch} if desired
  \item Populate the empty \texttt{connectors.kicad\_sch} sheet or remove it from the hierarchy
  \item Assign and verify all footprints in the KiCad project
  \item Generate netlist and begin PCB layout
  \item Separate ground planes: high-current motor ground physically isolated from logic ground with single star-point
  \item Ensure VMOT and VSTEP rails are clearly labelled on silkscreen
  \item Plan PCB size to accommodate all expansion port headers ($\sim$130$\times$95\,mm estimated)
  \item Add solder-bridge jumper for CAN 120\,$\Omega$ termination
  \item Mark BOOT0 / RESET buttons clearly on silkscreen
\end{itemize}

\subsection{Firmware}

\begin{itemize}
  \item STM32 HAL/LL bringup: I$^2$C scan (all 16 expansion ports), PWM test, CAN loopback, UART echo
  \item TMC2209 UART configuration driver for per-application current tuning
  \item BMI270 SPI driver + Madgwick / Mahony filter for attitude estimation
  \item ESP32-C3 SPI bridge firmware --- define message protocol to/from STM32
  \item Implement reverse-ARP HAL for TCA9548A expansion array
  \item Define HAL API: \texttt{i2c\_port\_scan\_all()}, \texttt{i2c\_port\_read(port, addr, reg, len)}, \texttt{i2c\_port\_write(port, addr, reg, data, len)}
  \item Generate full LCSC / Mouser priced BOM from this document for procurement
\end{itemize}

% ─────────────────────────────────────────────────────────────────────────────
\appendix

\section{\texorpdfstring{I$^2$C}{I2C} Address Map}

\rowcolors{2}{rowalt}{white}
\begin{longtable}{p{2.5cm} p{3.5cm} p{3cm} p{6cm}}
  \toprule
  \rowcolor{headergray}\color{white}\textbf{Address} &
  \color{white}\textbf{Device} &
  \color{white}\textbf{Bus Location} &
  \color{white}\textbf{Notes} \\
  \midrule\endhead
  0x20 & PCF8574DW         & Main bus (fixed) & 8-ch digital GPIO expander \\
  0x3C & OLED display       & Main bus (fixed) & 0.96\,'' OLED header --- user-supplied \\
  0x40 & PCA9685PW         & Main bus (fixed) & 16-ch servo PWM driver \\
  0x48 & ADS1115IDGST      & Main bus (fixed) & 4$\times$ 16-bit analogue ADC \\
  0x70 & TCA9548APWR Mux\,\#1 & Main bus (fixed) & 8-ch I$^2$C mux --- ports 0--7 \\
  0x71 & TCA9548APWR Mux\,\#2 & Main bus (fixed) & 8-ch I$^2$C mux --- ports 8--15 \\
  Various & User devices   & Expansion ports 0--15 & No conflicts between ports \\
  \midrule
  \multicolumn{4}{l}{\textit{Not on I$^2$C:} BMI270 (SPI, spi\_bus sheet) --- \textit{no longer on the I$^2$C bus.}} \\
  \bottomrule
\end{longtable}

\section{Schematic Sheet Structure}

\rowcolors{2}{rowalt}{white}
\begin{longtable}{p{3.5cm} p{4.5cm} p{7cm}}
  \toprule
  \rowcolor{headergray}\color{white}\textbf{Sheet Name} &
  \color{white}\textbf{File} &
  \color{white}\textbf{Contents} \\
  \midrule\endhead
  Root         & \texttt{Robodev.kicad\_sch}   & Top-level interconnect, mounting holes (H1--H4) \\
  power        & \texttt{power.kicad\_sch}      & XT60 input, IRF4905 reverse protect, slide switch, XL4016$\times$2, LM2596T-5, AP2112K-3.3, all bulk caps \\
  stm32        & \texttt{esp32.kicad\_sch}      & STM32G431RBTx, SN65HVD230D CAN, USB4085-GF-A, SWD header, UART headers, ADC headers, encoder headers, GPIO header, BOOT0/RESET buttons \\
  spi\_bus     & \texttt{spi\_bus.kicad\_sch}   & ESP32-C3-MINI-1-N4, BMI270 IMU, 74HC595 shift register \\
  i2c\_bus     & \texttt{i2c\_bus.kicad\_sch}   & TCA9548APWR$\times$2 muxes, ADS1115IDGST ADC, PCF8574DW GPIO expander, all I$^2$C expansion headers (QWIIC + 2.54\,mm), OLED header \\
  motor\_dc    & \texttt{motor\_dc.kicad\_sch}  & DRV8874PWPR$\times$4, motor screw terminals, nFAULT LED, bulk capacitors \\
  motor\_stepper & \texttt{motor\_stepper.kicad\_sch} & TMC2209-LA-T$\times$2, stepper output headers \\
  motor\_servo & \texttt{motor\_servo.kicad\_sch} & PCA9685PW, 16$\times$ servo headers \\
  connectors   & \texttt{connectors.kicad\_sch} & (Currently empty --- reserved for future use) \\
  \bottomrule
\end{longtable}

\end{document}

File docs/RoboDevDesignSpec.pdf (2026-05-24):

# RoboDev

STM32G431 + ESP32-C3 Integrated Robotics Prototyping Board

Design Specification | v0.8 | May 2026
Status | Schematic substantially complete — PCB layout not yet started
MCU | STM32G431RBTx (primary) + ESP32-C3-MINI-1-N4 (WiFi co-processor)
Repo | https://github.com/alexbnz-1/RoboDev

RoboDev — Design Specification | v0.8 · May 2026

## Contents

Revision History | 3
1 Introduction | 3
2 System Overview | 4
3 Power Architecture | 5
4 Microcontrollers | 6
5 Signal Interface Summary | 7
6 Motor Control | 8
7 Communication Interfaces | 10
8 Sensing and Analogue Inputs | 11
9 I²C Expansion Array | 12
10 Connector Reference | 13
11 Bill of Materials (v0.8) | 14

12 Recommended Improvements | 15
13 Open Questions and Next Steps | 15
A I²C Address Map | 16
B Schematic Sheet Structure | 16

## Revision History

Version | Date | Summary of Changes
v0.1 | Mar 2026 | Initial document from notebook notes (22 Oct – 17 Nov 2025).
v0.2 | Mar 2026 | DRV8245-Q1 → DRV8874. MPU-6050 → BMI270.
v0.3 | Mar 2026 | Soldered WROOM module → ESP32-S3 DevKitC-1 v1.1 in dual-row headers.
v0.4 | Mar 2026 | NEMA 17 stepper support: 2× TMC2209, GPIO26–31 allocated.
v0.5 | Mar 2026 | MPU-6050 GY-521 replaces BMI270. ADS1115, PCF8574, OLED header. Servos 8→16. SPI/UART/carrier USB-C removed. 5× ADC1 headers.
v0.6 | Mar 2026 | CAN bus (TWAI, GPIO7/32, SN65HVD230). Encoders 4→2. nFAULT→indicator LED. UART1 header (GPIO47/21). GPIO38/48 written off. Separate Vmot-DC and Vstep rails. 0 spare GPIOs. BOM ~NZ$82.81.
v0.7 | Mar 2026 | ⋆ I 2C expansion array: 2× TCA9548A mux (0x70/0x71) + 6× Qwiic JST SH + 10× 2.54 mm 4-pin headers = 16 independent expansion ports. Reverse-ARP HAL for automatic peripheral discovery. BOM ~NZ$90–92.
v0.8 | May 2026 | ⋆ Dual-MCU architecture: STM32G431RBTx replaces ESP32-S3 as primary MCU. ESP32-C3-MINI-1-N4 added as SPI-attached WiFi/BT co-processor. BMI270 IMU moves to SPI (co-processor sheet). USB4085-GF-A Type-C on carrier. SWD debug port added. XT60PW-M replaces XT30 power connector. IRF4905 PMOS reverse protection. 74HC595 shift register added. XL4016 ×2 for VMOT + VSTEP. KiCad schematic implementation begun (all major blocks drawn).

## 1 Introduction

RoboDev is an open-source integrated robotics prototyping board built around a dual-MCU architecture: an STMicroelectronics STM32G431RBTx Cortex-M4F as the primary motor control processor, and an Espressif ESP32-C3-MINI-1-N4 module as a SPI-attached WiFi and Bluetooth co-processor. It is designed to eliminate the wiring overhead that typically accompanies microcontroller-based robotics projects by integrating motor drivers, a servo PWM controller, stepper motor drivers, a CAN bus transceiver, an IMU, analogue ADC expanders, digital GPIO expansion, an I²C expansion array, and a complete multi-rail power supply onto a single carrier PCB.

The core philosophy of RoboDev is that only three types of wire should ever need to be connected to the board: power in, and wires out to sensors and actuators. All signal routing — from the MCU to driver ICs, from the I²C bus to peripherals, from the power switch to every rail — is handled on the PCB itself.

### 1.1 Motivation

Robotics prototyping typically requires a breadboard or custom wiring harness to connect motor driver breakout boards, servo controllers, and sensor modules. This introduces noise susceptibility, mechanical fragility, and significant bring-up time before any firmware can be tested. RoboDev solves this by providing a production-ready carrier board with the STM32G431RBTx at the centre — a Cortex-M4F processor from ST’s G4 series that is purpose-built for motor control and digital power conversion, with hardware PWM timers, FDCAN, and a hardware FPU.

Wireless connectivity is provided by the ESP32-C3-MINI-1-N4, mounted on the carrier and connected to the STM32 via SPI. This separation of concerns keeps the hard-real-time motor control tasks on the deterministic STM32 while offloading WiFi, Bluetooth, and any cloud connectivity tasks to the ESP32-C3.

### 1.2 Design Philosophy

- Full-featured and self-contained — no daughterboards or breakout modules required
- Dual-MCU architecture: STM32G431RBTx for real-time control; ESP32-C3-MINI-1-N4 for wireless
- Any motor type supported simultaneously: 4× brushed DC, 16× servo, 2× NEMA 17 stepper, and CAN-capable motor controllers
- BMI270 6-axis IMU on SPI for high-speed attitude estimation
- Three independently adjustable power rails for motors, steppers, and servos
- 16-port I²C expansion array via 2× TCA9548A mux (zero GPIO cost)
- All components hand-solderable — no BGA or ultra-fine-pitch packages
- Open source: schematics, PCB layout, firmware, and documentation on GitHub

### 1.3 Target Applications

- 2WD and 4WD wheeled robot platforms
- Multi-axis robot arms with CAN-capable joint controllers
- Mechatronics rigs requiring mixed motor types on a single controller
- Autonomous vehicles with wireless telemetry and IMU sensor fusion
- Sensor-dense robots using the I²C expansion array for multiple sensors
- Educational robotics platforms requiring a robust, well-documented base board

## 2 System Overview

RoboDev uses a two-MCU design. The STM32G431RBTx is the primary processor, handling all real-time motor control, CAN communication, sensor interfacing, and I²C bus management. The ESP32-C3-MINI-1-N4 sits alongside it on the carrier PCB, connected to the STM32 via SPI, and handles all WiFi and Bluetooth tasks.

The board is divided into eight functional domains: power management, primary MCU (STM32), WiFi co-processor (ESP32-C3), motor control (DC, stepper, servo), communication (I²C, CAN, UART), sensing (IMU, analogue, digital), expansion (Qwiic, GPIO headers), and the I²C expansion array.

### 2.1 Core Requirements Summary

Category | Requirement / Specification
Primary MCU | STM32G431RBTx · Cortex-M4F · 170 MHz · FPU · 128 KB Flash · LQFP-64
WiFi Co-processor | ESP32-C3-MINI-1-N4 · SPI-connected · 802.11b/g/n + Blue-tooth 5
DC Motors | 4 channels · DRV8874PWPR · 4.5–37 V · 2.1 A cont. / 6 A peak · nFAULT LED

Category | Requirement / Specification
Servos | 16 channels · PCA9685PW I²C PWM driver (0x40) · 12-bit resolution · 5 V servo rail
Stepper Motors | 2 channels · TMC2209-LA-T · NEMA 17 · 2 A RMS / 2.8 A peak · UART-configurable · StealthChop2
CAN Bus | FDCAN (ISO 11898-1) · SN65HVD230D 3.3 V transceiver · up to 1 Mbps · 5.08 mm screw terminal
IMU | BMI270 · 6-axis accel + gyro · SPI interface · on co-processor sheet
Quadrature Encoders | 2 channels · 4-pin 2.54 mm headers
Native Analogue ADC | 3× 2.54 mm headers · STM32 ADC inputs
I 2C Analogue ADC | 4 channels · ADS1115IDGST (0x48) · 16-bit · I 2C
GPIO Expander | 2C PCF8574DW (0x20) · 8-channel digital I/O · I
I 2C Expansion Array | 16 independent ports · 2× TCA9548APWR mux (0x70/0x71) · 3× Qwiic + 13× 2.54 mm · zero GPIO cost
USB | Type-C · USB4085-GF-A · on STM32 sheet
SWD Debug | 2.54 mm header · STM32 programming and debug
UART Headers | 2× 2.54 mm (debug + general purpose)
Shift Register | 74HC595 · 8-bit serial-in parallel-out · SPI-driven (ESP32-C3 sheet)
Power Input | XT60PW-M · reverse polarity protection (IRF4905 PMOS) · slide switch

## 3 Power Architecture

The power system is designed around four independent rails, each serving a distinct subsystem. Separating VMOT from VSTEP allows brushed DC motors and stepper motors to be run at different voltages simultaneously. All rails are derived from a single protected XT60 input, switched by a common high-current slide switch.

### 3.1 Power Input and Protection

Power enters the board via an XT60PW-M connector. Input voltage should be at least 6 V to allow headroom for the buck converter generating the 5 V logic rail. Do not exceed 36 V (the rated ceiling of the XL4016 buck converters).

An IRF4905 P-channel power MOSFET provides reverse voltage protection on VIN before the power switch. MBR2045CT Schottky diodes are used for power path management. An SS14 diode handles USB/power path arbitration.

Warning: A high-current slide switch (OS102011MS2QN1) is placed after the reverse voltage protection circuit. It switches all rails simultaneously. When laying out the PCB, ensure the switch trace width is adequate for the total system current.

### 3.2 Power Rails

Rail | Output | Current | Load | Key Component / Notes
VMOT | Adj. 4.5–24 V | 5 A+ cont. | DC Motors M1– M4 | XL4016 step-down · trimmer pot on FB · 470 µF bulk ×4
VSTEP | Adj. 4.5–24 V | 3 A+ cont. | Steppers S1–S2 | XL4016 step-down · indepen-dent rail
+5 V | Fixed 5 V | 3 A+ cont. | Servo rail, USB, ESP32-C3 | LM2596T-5 synchronous buck · 33 µH inductor
+3.3 V | Fixed 3.3 V | 1 A+ cont. | STM32, all ICs, sensors | AP2112K-3.3 LDO from 5 V · all I²C devices

Warning: VMOT and VSTEP are independent adjustable XL4016 buck converters. Each has its own trimmer potentiometer. Label both clearly on the PCB silkscreen to prevent accidental cross-connection.

### 3.3 Bulk Decoupling Capacitors

Each DRV8874 DC motor driver requires at least one electrolytic bulk capacitor rated for the VMOT voltage placed as close as possible to the VM pin. A minimum of 470 µF at 50 V is specified per driver. Each TMC2209 stepper driver similarly requires bulk capacitance on the VSTEP rail. All ICs additionally receive 100 nF ceramic decoupling capacitors.

## 4 Microcontrollers

### 4.1 Primary MCU — STM32G431RBTx

The STM32G431RBTx (U_MCU1) is a 64-pin LQFP Cortex-M4F microcontroller from STMicroelectronics’ G4 series. Running at 170 MHz with a hardware FPU, it is purpose-built for motor control and digital power conversion applications.

Note: The schematic sheet is labelled stm32 and uses file esp32.kicad_sch — a legacy filename from the earlier ESP32-S3 design. The actual placed component is STM32G431RBTx.

Key peripherals used on this board:

- Timers (TIM/HRTIM) — motor PWM generation for M1–M4 DC motor channels and S1–S2 stepper STEP pulses
- FDCAN — hardware CAN controller via SN65HVD230D transceiver
- I

2C — shared bus for PCA9685, ADS1115, PCF8574, TCA9548A ×2
- SPI — connection to ESP32-C3-MINI-1-N4 co-processor and 74HC595 shift register
- UART/USART — TMC2209 UART configuration interface + debug/general UART headers
- ADC — native ADC inputs broken out to 3× 2.54 mm headers
- USB FS — via USB4085-GF-A Type-C connector
- SWD — programming and debug via 2.54 mm header (J_SWD1)

The BOOT0 pin is pulled to GND via a 10 kΩ resistor with a MJTP1230 push-button to allow entry into the DFU bootloader. A separate MJTP1230 provides system RESET. A 100 nF capacitor is placed on the NRST pin.

### 4.2 WiFi Co-processor — ESP32-C3-MINI-1-N4

The ESP32-C3-MINI-1-N4 (on the spi_bus sheet) provides 802.11b/g/n WiFi and Bluetooth 5 LE connectivity. It is connected to the STM32 via SPI, with the following interface signals:

- SPI_SCK, SPI_MOSI, SPI_MISO — SPI bus to/from STM32
- SPI_CS — chip select from STM32
- SPI_LATCH — latch signal (also drives 74HC595 shift register)
- WIFI_IRQ — interrupt output from ESP32-C3 to STM32

The ESP32-C3 also connects to the BMI270 IMU and the 74HC595 shift register on its sheet.

4.3 74HC595 Shift Register

A 74HC595 8-bit serial-in parallel-out shift register is placed on the spi_bus sheet alongside the ESP32-C3. It is clocked via the SPI bus (or the SPI_LATCH signal), providing 8 additional digital output lines without consuming extra GPIO on the STM32. Typical use cases include status LEDs, output expansion, and simple digital control signals.

## 5 Signal Interface Summary

The following table lists the hierarchical sheet pin names that cross between sheets in the KiCad schematic. Exact STM32 pin numbers are TBD (to be verified during PCB layout).

Signal | Dir. | Sheet | Function
M1_PWM / M1_DIR | Out | stm32 → mo-tor_dc | DC motor M1 PWM + direction
M2_PWM / M2_DIR | Out | stm32 → mo-tor_dc | DC motor M2 PWM + direction
M3_PWM / M3_DIR | Out | stm32 → mo-tor_dc | DC motor M3 PWM + direction
M4_PWM / M4_DIR | Out | stm32 → mo-tor_dc | DC motor M4 PWM + direction
S1_STEP/DIR/EN | Out | stm32 → mo-tor_stepper | Stepper S1 control
S2_STEP/DIR/EN | Out | stm32 → mo-tor_stepper | Stepper S2 control
TMC_UART_TX/RX Bidir | | stm32 ↔ mo-tor_stepper | TMC2209 UART config bus
I2C_SCL/SDA | Out | stm32 → i2c_bus, motor_servo | Shared I²C bus
SPI_CS/MOSI/MISO/SCK Bidir | | stm32 ↔ spi_bus | SPI to ESP32-C3 + 74HC595
SPI_LATCH | Out | stm32 → spi_bus | 74HC595 latch
WIFI_IRQ | In | spi_bus → stm32 | ESP32-C3 interrupt
IMU_INT1 | In | spi_bus → stm32 | BMI270 interrupt
GPIO_INT | In | i2c_bus → stm32 | PCF8574 interrupt
IPROPI_M1–M4 | In | motor_dc → i2c_bus | DRV8874 current sense to ADS1115
VMOT | Pwr | power → mo-tor_dc | DC motor power rail

Signal | Dir. | Sheet | Function
VSTEP | Pwr | power → mo-tor_stepper | Stepper power rail
VSERVO | Pwr | power → mo-tor_servo | Servo power rail
VBUS / ADC_VIN | Pwr | power → stm32 | USB bus power + ADC reference

## 6 Motor Control

### 6.1 DC Brushed Motors — DRV8874PWPR × 4

Four DRV8874PWPR H-bridge motor driver ICs (U_M1–U_M4) provide control for four independent brushed DC motor channels (M1–M4). The DRV8874 is a fully integrated H-bridge with hardware overcurrent protection, thermal shutdown, and undervoltage lockout.

Parameter | Value / Detail
Part number | DRV8874PWPR (HTSSOP-16)
Supply voltage (VM) | 4.5 V – 37 V (VMOT rail)
Continuous current | 2.1 A per channel
Peak current | 6 A per channel
Control M1 | M1_PWM (PWM/Phase), M1_DIR (DIR/Enable) from STM32
Control M2 | M2_PWM, M2_DIR
Control M3 | M3_PWM, M3_DIR
Control M4 | M4_PWM, M4_DIR
Output connector | 2-pin 5.08 mm screw terminal per channel
nFAULT handling | All 4 nFAULT pins wired-OR open-drain → red indicator LED (LTST-C190KRKT). No MCU GPIO consumed.
Bulk capacitance | 470 µF 50 V electrolytic per driver (C_VM1–C_VM4), close to VM pin
Current sense | IPROPI output routed to ADS1115 (A6–A9) for per-motor current monitoring

### 6.2 NEMA 17 Stepper Motors — TMC2209-LA-T × 2

Two TMC2209-LA-T silent stepper motor driver ICs (U_S1–U_S2) drive two NEMA 17 bipolar stepper motors from the independent VSTEP rail. The TMC2209 features StealthChop2 for near-silent operation and SpreadCycle for high-torque applications, configurable via UART.

Parameter | Value / Detail
Part number | TMC2209-LA-T (QFN-28)
Supply voltage (VM) | 4.5 V – 36 V (VSTEP rail — independent from VMOT)
RMS current | 2.0 A RMS per channel
Peak current | 2.8 A peak per channel
Control S1 | S1_STEP, S1_DIR, S1_EN (active LOW)
Control S2 | S2_STEP, S2_DIR, S2_EN (active LOW)
EN pull-up | 10 kΩ to 3.3 V — drivers disabled by default at power-on

Parameter | Value / Detail
UART config | TMC_UART_TX/RX to STM32 (optional per-application current tuning)
Bulk capacitance | 100 µF 35 V+ per driver

Note: The VSTEP rail is intentionally separate from VMOT. This allows, for example, 12 V NEMA 17 operation alongside 6 V DC gearmotors simultaneously.

### 6.3 Servo Motors — PCA9685PW × 16

A PCA9685PW 16-channel 12-bit PWM driver IC provides servo control for up to 16 hobby servo channels simultaneously via I²C. All 16 PWM outputs are broken out to 3-pin 2.54 mm servo headers carrying GND, VSERVO, and PWM signal.

Parameter | Value / Detail
Part number | PCA9685PW (TSSOP-28)
I 2C address | 0x40 (ADDR pins → GND)
PWM resolution | 12-bit (4096 steps)
PWM frequency | Configurable 24 Hz – 1526 Hz (typically 50 Hz for standard servos)
Servo voltage | VSERVO (derived from +5 V rail via MBR2045CT protection diode)
Servo headers | 3-pin 2.54 mm GND / VSERVO / PWM (16 channels)
Control interface | 2C via STM32 I²C bus I

### 6.4 Motor Compatibility

Motor Type | Compatible?Notes
TT yellow gearmotors (2WD/4WD) | ✓ | Common chassis motors — ideal fit
Pololu micro/mini DC gearmotors | ✓ | Well within DRV8874 2.1 A continuous rat-ing
25 mm / 37 mm DC gearmotors | ✓* | Stall may approach 6 A peak — current limiting recommended
775-size DC motors | × | Exceeds DRV8874 continuous rating — use external driver
Hobby servos (3–8.4 V) | ✓ | PCA9685 servo rail, up to 16 channels si-multaneously
NEMA 17 stepper motors | ✓ | TMC2209 StealthChop2 · up to 2 A RMS / 2.8 A peak
CAN motor controllers (VESC, ODrive) | ✓ | FDCAN via SN65HVD230D · ISO 11898-1

## 7 Communication Interfaces

### 7.1 I

2C Bus

A single I²C bus from the STM32 carries all on-board I²C peripherals plus the TCA9548A expansion array. Pull-up resistors of 4.7 kΩ to 3.3 V are provided on-board.

Device | Addr. | Function | Notes
PCA9685PW | 0x40 | 16-ch servo PWM driver | Main bus — always visible
ADS1115IDGST | 0x48 | 4-ch 16-bit ADC | Main bus — ADDR→GND
PCF8574DW | 0x20 | 8-ch digital GPIO ex-pander | Main bus — INT to STM32 (GPIO_INT)
OLED display | 0x3C | 0.96 ” display (user-supplied) | 4-pin 2.54 mm header (J_OLED1)
TCA9548APWR Mux #1 | 0x70 | I 2C mux — ports 0–7 | Main bus — always visible
TCA9548APWR Mux #2 | 0x71 | I 2C mux — ports 8–15 | Main bus — always visible
Expansion 0–15 | Any | User I²C devices | Behind mux — no address conflicts

Note: The BMI270 IMU is on SPI, not I²C. It is located on the spi_bus sheet alongside the ESP32-C3. The main I²C bus has seven on-board devices; no address conflicts exist between them.

### 7.2 CAN Bus (FDCAN)

CAN bus support is implemented using the STM32G431’s built-in FDCAN controller, conforming to ISO 11898-1. An SN65HVD230D 3.3 V CAN transceiver provides the physical layer.

Parameter | Value / Detail
Protocol | ISO 11898-1 (CAN 2.0A/B / CAN FD capable) via STM32 FDCAN hardware
Transceiver | SN65HVD230D (SOIC-8, 3.3 V compatible, up to 1 Mbps)
Bus connector | 5.08 mm 2-pin screw terminal (J_CAN1) — CANH / CANL
Termination | 120 Ω resistor (R_CAN_TERM1) on board
Logic level | 3.3 V — directly compatible with STM32G431 GPIO
Use cases | CAN motor controllers (VESC, ODrive), robot arm joints, inter-board comms

Warning: Do not substitute the SN65HVD230D with a 5 V transceiver such as the MCP2551. The STM32G431 GPIO pins are 3.3 V tolerant; a 5 V transceiver output will permanently damage the MCU.

### 7.3 USB (Type-C)

A USB4085-GF-A USB Type-C connector (X1) on the STM32 sheet provides USB Full-Speed connectivity directly to the STM32G431’s USB FS peripheral. This is used for firmware programming (DFU bootloader via BOOT0 button) and virtual COM port (VCP) communication.

### 7.4 SWD Debug Interface

A 4-pin 2.54 mm SWD header (J_SWD1) exposes the STM32G431’s Serial Wire Debug interface (SWDIO / SWDCLK / GND / 3.3 V). This supports programming and live debugging via ST-LINK, J-Link, or compatible probe.

### 7.5 UART Headers

- J_UART_DBG1 — UART debug port (4-pin 2.54 mm). Intended for serial monitor and low-level firmware diagnostics.
- J_UART2 — General-purpose UART header (4-pin 2.54 mm). Use for GPS (NMEA), LiDAR (RPLIDAR, TF-Luna), or any UART-based peripheral.

## 8 Sensing and Analogue Inputs

### 8.1 Inertial Measurement Unit — BMI270

The BMI270 6-axis IMU is placed on the spi_bus sheet alongside the ESP32-C3-MINI-1-N4. It provides 3-axis accelerometer and 3-axis gyroscope data via SPI. An interrupt output (IMU_INT1) is routed to the STM32 for data-ready notification.

- Interface: SPI
- Interrupt: IMU_INT1 → STM32
- Firmware: BMI270 SPI driver recommended; Madgwick or Mahony filter for attitude estimation

### 8.2 Native Analogue Inputs — ADC Headers

Three 2.54 mm headers (J_ADC1, J_ADC2, J_ADC3) break out STM32G431 ADC input channels. Exact GPIO assignments are to be determined during schematic finalisation and PCB layout.

- Pinout: GND / 3.3 V / SIG (3-pin headers)
- Resolution: 12-bit (STM32 ADC1/ADC2)

### 8.3 I

2C Analogue Inputs — ADS1115IDGST

The ADS1115IDGST 16-bit I²C ADC (U_ADC1) provides four additional analogue channels (A6–A9) at significantly higher resolution than the native ADC. The DRV8874 IPROPI current sense outputs are routed here for per-motor current monitoring.

- I

2C address: 0x48 (ADDR→GND)
- Resolution: 16-bit (±32767 counts), programmable gain: ±0.256 V to ±6.144 V FSR
- IPROPI inputs: IPROPI_M1–M4 from DRV8874 → ADS1115 (via i2c_bus sheet)

### 8.4 PCF8574DW — Digital GPIO Expander

The PCF8574DW (U_GPIO1) provides 8 additional digital I/O lines via I²C at address 0x20. An INT signal is routed to the STM32 (GPIO_INT) for interrupt-driven pin change notification. A pull-up resistor (R_GPIO_INT1) is placed on the INT line.

### 8.5 Quadrature Encoders

Two quadrature encoder channels are supported. Each channel provides a 4-pin 2.54 mm header (J_ENC1, J_ENC2) with pinout GND / 3.3 V / Chan-A / Chan-B.

### 8.6 GPIO Header

A general-purpose GPIO header (J_GPIO1) breaks out additional STM32 GPIO pins for user-defined digital I/O.

## 9 I

## 2C Expansion Array

Two TCA9548APWR 8-channel I²C multiplexers (U_MUX1 at 0x70, U_MUX2 at 0x71) are added to the main I²C bus. Each provides 8 independently switched downstream channels, giving 16 expansion ports total. Each port is a fully isolated I²C segment — devices on different ports can share the same I²C address without conflict.

### 9.1 Expansion Port Layout

Port | Connector | Mux Channel | Isolation | Notes
0 | QWIIC JST SH 4-pin | TCA9548A #1 Ch0 | Independent | QWIIC port 1 on Mux #1
1 | QWIIC JST SH 4-pin | TCA9548A #1 Ch1 | Independent | QWIIC port 2 on Mux #1
2 | QWIIC JST SH 4-pin | TCA9548A #1 Ch2 | Independent | QWIIC port 3 on Mux #1
3 | 2.54 mm 4-pin | TCA9548A #1 Ch3 | Independent | GND/3.3 V/SDA/SCL
4 | 2.54 mm 4-pin | TCA9548A #1 Ch4 | Independent
5 | 2.54 mm 4-pin | TCA9548A #1 Ch5 | Independent
6 | 2.54 mm 4-pin | TCA9548A #1 Ch6 | Independent
7 | 2.54 mm 4-pin | TCA9548A #1 Ch7 | Independent
8 | QWIIC JST SH 4-pin | TCA9548A #2 Ch0 | Independent | QWIIC port 1 on Mux #2
9 | 2.54 mm 4-pin | TCA9548A #2 Ch1 | Independent
10 | 2.54 mm 4-pin | TCA9548A #2 Ch2 | Independent
11 | 2.54 mm 4-pin | TCA9548A #2 Ch3 | Independent
12 | 2.54 mm 4-pin | TCA9548A #2 Ch4 | Independent
13 | 2.54 mm 4-pin | TCA9548A #2 Ch5 | Independent
14 | 2.54 mm 4-pin | TCA9548A #2 Ch6 | Independent
15 | 2.54 mm 4-pin | TCA9548A #2 Ch7 | Independent

### 9.2 TCA9548A Architecture

Parameter | Value / Detail
Part number | TCA9548APWR (TSSOP-24)
2C address Mux #1 I | 0x70 (A2/A1/A0 = 0/0/0 → GND)
2C address Mux #2 I | 0x71 (A2/A1/A0 = 0/0/1 → Mux #2 A0 → 3.3 V)
Channels per IC | 8 independent I²C downstream channels
Total expansion ports | 16 (8 from Mux #1 + 8 from Mux #2)
Supply voltage | 3.3 V
Pull-up resistors | 4.7 kΩ on SDA/SCL of main bus only (mux outputs are active)

Parameter | Value / Detail
Address conflict risk | None between ports — each port is on an independently switched segment
Reset pull-ups | 10 kΩ pull-ups on /RESET pins of both TCA9548A ICs

### 9.3 Reverse-ARP HAL — Automatic Peripheral Discovery

The firmware HAL implements a reverse-ARP discovery mechanism for the expansion array. On startup, the HAL iterates through all 16 expansion ports, temporarily enables each channel, performs an I²C scan, records any device addresses found, and then disables the channel. The result is a port map that application code can query.

- On startup: scan all 16 ports → build port map → log device addresses per port
- At runtime: request i2c_port_N → HAL enables TCA9548A channel → performs transaction → disables channel
- No address conflicts possible — HAL enforces single-channel activation

Warning: Only one TCA9548A channel should be active at any time. The HAL enforces this. Do not manually write to the TCA9548A channel registers from application code while the HAL is active.

## 10 Connector Reference

Ref | Type | Qty | Pitch | Function / Pinout
J_XT60 | XT60PW-M | 1 | XT60 | VIN power input
J_CAN1 | Screw terminal | 1 | 5.08 mm 2-pin | CAN: CANH / CANL
J_ENC1, J_ENC2 | Pin header | 2 | 2.54 mm 4-pin | Encoders: GND / 3.3 V / Chan-A / Chan-B
J_UART_DBG1 | Pin header | 1 | 2.54 mm 4-pin | UART debug: GND / 3.3 V / TX / RX
J_UART2 | Pin header | 1 | 2.54 mm 4-pin | UART general: GND / 3.3 V / TX / RX
J_OLED1 | Pin header | 1 | 2.54 mm 4-pin | OLED: GND / 3.3 V / SDA / SCL
J_SWD1 | Pin header | 1 | 2.54 mm 4-pin | SWD: GND / 3.3 V / SWDIO / SWDCLK
J_ADC1– J_ADC3 | Pin header | 3 | 2.54 mm 3-pin | ADC: GND / 3.3 V / SIG
J_GPIO1 | Pin header | 1 | 2.54 mm 4-pin | Direct GPIO header
Servo headers | Pin header | 16 | 2.54 mm 3-pin | Servo: GND / VSERVO / PWM
Motor terminals | Screw terminal | 4 | 5.08 mm 2-pin | DC motor outputs M1–M4
Stepper headers | Pin header | 2 | 2.54 mm 4-pin | STEP/DIR/EN per stepper
J_MUX1_CH0– CH7 | Mixed | 8 | QWIIC / 2.54 mm | I 2C expansion ports 0–7
J_MUX2_CH0– CH7 | Mixed | 8 | QWIIC / 2.54 mm | I 2C expansion ports 8–15

Ref | Type | Qty | Pitch | Function / Pinout
X1 | USB Type-C | 1 | USB4085-GF-A | USB FS / DFU programming
H1–H4 | Mounting hole | 4 | M3 pad | Grounded M3 mounting holes

## 11 Bill of Materials (v0.8)

Estimated mid-range unit pricing at Qty = 1. Excludes PCB assembly labour, shipping, and import duties. Rows highlighted in blue are new or significantly changed in v0.8.

# | Component | Part Number | Qty | Notes

1 | STM32G431RBTx MCU | STM32G431RBTx (LQFP-64) | 1 | Primary MCU, 170 MHz Cortex-M4F
2 | ESP32-C3-MINI-1-N4 | ESP32-C3-MINI-1-N4 | 1 | WiFi/BT co-processor, SPI inter-face
3 | DRV8874 H-Bridge | DRV8874PWPR (HTSSOP-16) | 4 | DC motors M1–M4
4 | SN65HVD230 CAN | SN65HVD230D (SOIC-8) | 1 | CAN bus transceiver
5 | CAN screw terminal | 5.08 mm 2-pin | 1 | CANH / CANL
6 | nFAULT LED | LTST-C190KRKT Red | 1 | DRV8874 fault indicator
7 | PCA9685 servo driver | PCA9685PW (TSSOP-28) | 1 | 16-ch PWM servo
8 | ADS1115 ADC | ADS1115IDGST (MSOP-10) | 1 | 16-bit I²C ADC, motor current sense
9 | PCF8574 GPIO expander | PCF8574DW (SOIC-16) | 1 | 8-ch digital I/O expander
10 | TCA9548A I²C Mux | TCA9548APWR (TSSOP-24) | 2 | Mux #1 (0x70), Mux #2 (0x71)
11 | QWIIC header | JST SH SM04B-SRSS-TB | 3 | 2C expansion QWIIC ports I
12 | Expansion 2.54 mm headers | 4-pin 2.54 mm | 13 | 2C expansion headers I
13 | BMI270 IMU | BMI270 | 1 | 6-axis IMU, SPI interface
14 | 74HC595 shift register | 74HC595 | 1 | 8-bit serial output expander
15 | USB Type-C connector | USB4085-GF-A | 1 | USB FS / DFU
16 | XT60 power connector | XT60PW-M | 1 | Main power input
17 | IRF4905 PMOS | IRF4905 | 1 | Reverse polarity protection
18 | MBR2045CT Schottky | MBR2045CT | 1+ | Power path protection
19 | SS14 Schottky diode | SS14 | 1 | USB power path
20 | OS102011MS2QN1 switch | OS102011MS2QN1 | 1 | Main power slide switch
21 | MJTP1230 pushbutton | MJTP1230 | 2 | BOOT0 + RESET buttons
22 | XL4016 buck converter | XL4016 | 2 | VMOT + VSTEP adjustable rails
23 | LM2596T-5 buck | LM2596T-5 | 1 | Fixed 5 V logic rail
24 | AP2112K-3.3 LDO | AP2112K-3.3 (SOT-25) | 1 | Fixed 3.3 V logic
25 | 33 µH / 4 A inductor | – | 1 | 5 V buck output filter

# | Component | Part Number | Qty | Notes

26 | 47 µH / 12 A inductor | – | 2 | VMOT / VSTEP buck output fil-ters
27 | Electrolytic cap 470 µF 50 V | – | 3+ | Motor/bulk capacitors
28 | Electrolytic cap 680 µF 50 V | – | 1 | VIN bulk input cap
29 | Electrolytic cap 220 µF 25 V | – | 1 | 5 V rail bulk cap
30 | Bourns 3296W trimmer 10 kΩ | Bourns 3296W | 2+ | VMOT / VSTEP feedback di-viders
31 | 100 nF ceramic 0603 (×25) | GRM188R71C104 | 25 | IC bypass decoupling
32 | Resistor assortment 0603 (×40) | Misc. | 40 | Pull-ups, dividers, LED limiting
33 | 2-layer PCB ~130×95 mm | JLCPCB / PCBWay | 1 | Design TBD

## 12 Recommended Improvements

Improvement | Priority | Notes
Battery voltage monitor | High | Resistor divider on VIN → any ADC header. Zero GPIO cost.
Per-motor IPROPI cur-rent sense | High | DRV8874 IPROPI → ADS1115. Already routed in schematic (IPROPI_M1–M4).
LiPo XT60 connector | Medium | XT60PW-M already placed. Consider adding balancer connector header.
On-board buzzer | Low | Requires an available GPIO. Assign from freed signals during layout.
WS2812B RGB status LED | Low | ESP32-C3 has spare GPIOs — can drive RGB LED without loading STM32.
CAN bus termination option | Medium | 120 Ω R_CAN_TERM1 already placed. Add solder-bridge jumper to enable/disable.

## 13 Open Questions and Next Steps

### 13.1 Verification Required

- Confirm all STM32G431RBTx pin assignments in schematic (ESP32-S3 pin table is obsolete)
- Prototype I²C bus — verify all 6 on-board device addresses and pull-up values at full loading
- Prototype CAN bus — verify SN65HVD230D wiring and FDCAN firmware configuration (bitrate, mode)
- Verify TCA9548A address selection resistors for 0x70 (all pins→GND) and 0x71 (A0→3.3 V)
- Test SPI interface between STM32 and ESP32-C3 — confirm protocol, clock speed, and IRQ behaviour
- Confirm BMI270 SPI routing and interrupt (IMU_INT1) behaviour

### 13.2 KiCad / PCB Design Tasks

- Review and clean up esp32.kicad_sch — rename sheet from “stm32” to something less confusing; rename file from esp32.kicad_sch if desired
- Populate the empty connectors.kicad_sch sheet or remove it from the hierarchy
- Assign and verify all footprints in the KiCad project
- Generate netlist and begin PCB layout
- Separate ground planes: high-current motor ground physically isolated from logic ground with single star-point
- Ensure VMOT and VSTEP rails are clearly labelled on silkscreen
- Plan PCB size to accommodate all expansion port headers (∼130×95 mm estimated)
- Add solder-bridge jumper for CAN 120 Ω termination
- Mark BOOT0 / RESET buttons clearly on silkscreen

### 13.3 Firmware

- STM32 HAL/LL bringup: I²C scan (all 16 expansion ports), PWM test, CAN loopback, UART echo
- TMC2209 UART configuration driver for per-application current tuning
- BMI270 SPI driver + Madgwick / Mahony filter for attitude estimation
- ESP32-C3 SPI bridge firmware — define message protocol to/from STM32
- Implement reverse-ARP HAL for TCA9548A expansion array
- Define HAL API: i2c_port_scan_all(), i2c_port_read(port, addr, reg, len), i2c_port_write(port, addr, reg, data, len)
- Generate full LCSC / Mouser priced BOM from this document for procurement

A I

## 2C Address Map

Address | Device | Bus Location | Notes
0x20 | PCF8574DW | Main bus (fixed) | 8-ch digital GPIO expander
0x3C | OLED display | Main bus (fixed) | 0.96 ” OLED header — user-supplied
0x40 | PCA9685PW | Main bus (fixed) | 16-ch servo PWM driver
0x48 | ADS1115IDGST | Main bus (fixed) | 4× 16-bit analogue ADC
0x70 | TCA9548APWR Mux #1 | Main bus (fixed) | 8-ch I²C mux — ports 0–7
0x71 | TCA9548APWR Mux #2 | Main bus (fixed) | 8-ch I²C mux — ports 8–15
Various | User devices | Expansion ports 0– 15 | No conflicts between ports

Not on I²C: BMI270 (SPI, spi_bus sheet) — no longer on the I²C bus.

## B Schematic Sheet Structure

Sheet Name | File | Contents
Root | Robodev.kicad_sch | Top-level interconnect, mounting holes (H1–H4)

Sheet Name | File | Contents
power | power.kicad_sch | XT60 input, IRF4905 reverse protect, slide switch, XL4016×2, LM2596T-5, AP2112K-3.3, all bulk caps
stm32 | esp32.kicad_sch | STM32G431RBTx, SN65HVD230D CAN, USB4085-GF-A, SWD header, UART headers, ADC headers, encoder headers, GPIO header, BOOT0/RESET buttons
spi_bus | spi_bus.kicad_sch | ESP32-C3-MINI-1-N4, BMI270 IMU, 74HC595 shift register
i2c_bus | i2c_bus.kicad_sch | TCA9548APWR×2 muxes, ADS1115IDGST ADC, PCF8574DW GPIO expander, all I²C expansion headers (QWIIC + 2.54 mm), OLED header
motor_dc | motor_dc.kicad_sch | DRV8874PWPR×4, motor screw termi-nals, nFAULT LED, bulk capacitors
motor_stepper | motor_stepper.kicad_sch | TMC2209-LA-T×2, stepper output head-ers
motor_servo | motor_servo.kicad_sch | PCA9685PW, 16× servo headers
connectors | connectors.kicad_sch | (Currently empty — reserved for future use)

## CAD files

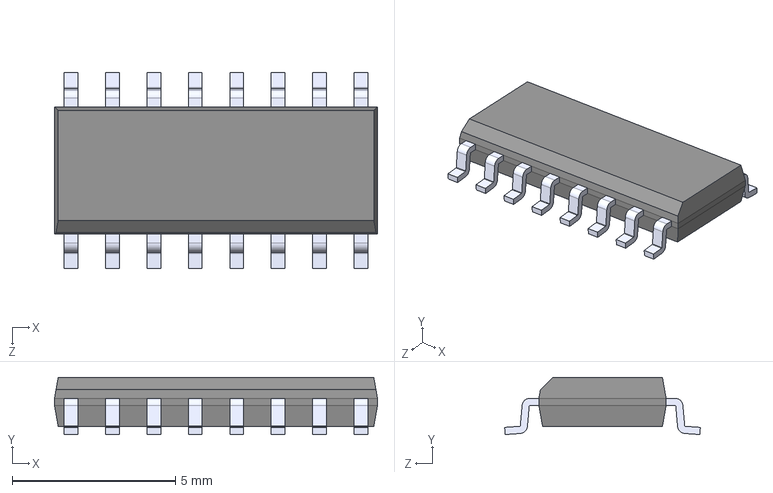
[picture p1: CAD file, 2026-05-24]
hardware/Components/74HC595/74HC595.step
9.90 x 1.75 x 6.00 mm

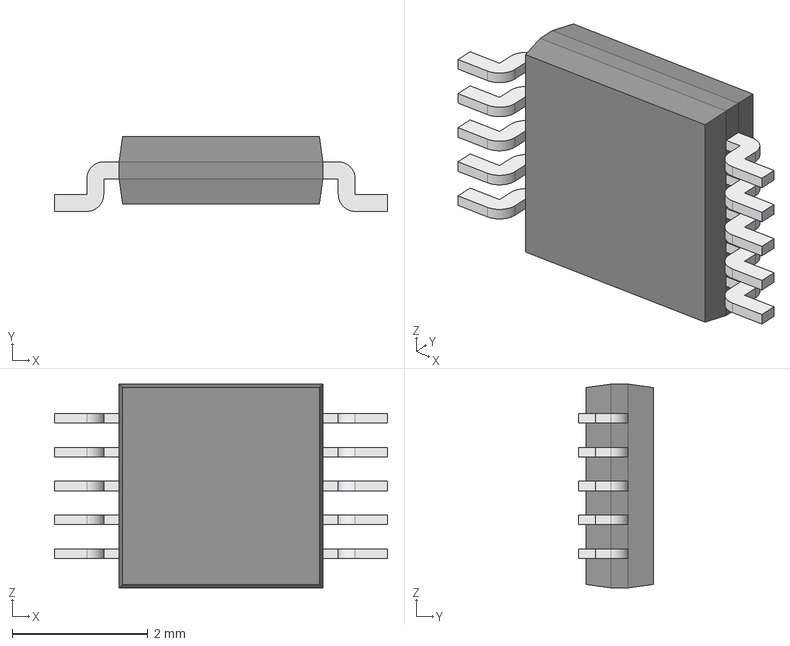
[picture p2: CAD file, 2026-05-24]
hardware/Components/ADS1115IDGST/ADS1115IDGST.step
4.90 x 1.10 x 3.00 mm
Body001 (Mirror #1) x 5
XY-plane x 12
X-axis x 12

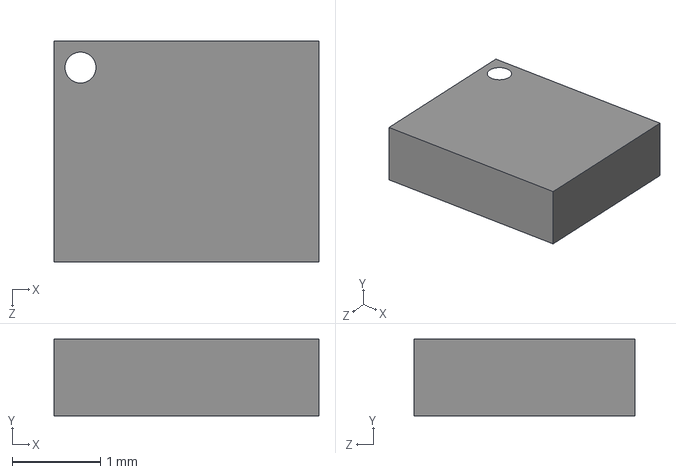
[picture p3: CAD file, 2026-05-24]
hardware/Components/BMI270/BMI270.step
3.00 x 0.87 x 2.50 mm

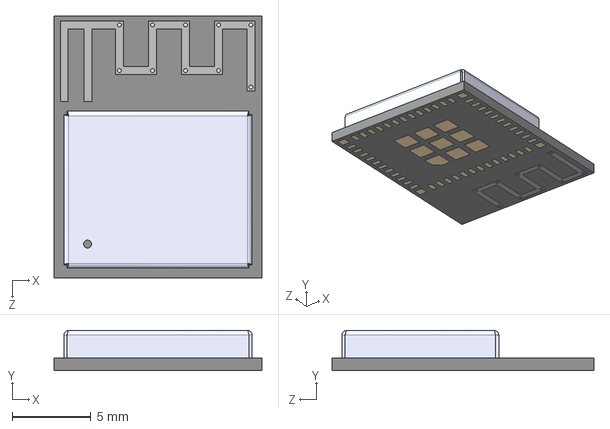
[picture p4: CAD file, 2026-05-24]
hardware/Components/ESP32-C3-MINI-1-N4/ESP32-C3-MINI-1-N4.step
13.2 x 2.55 x 16.6 mm

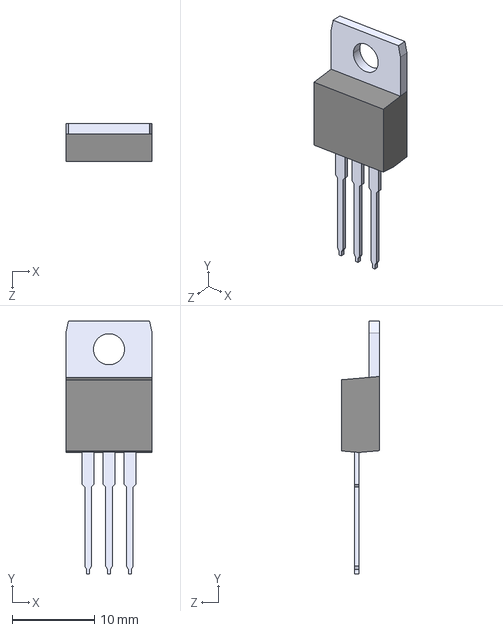
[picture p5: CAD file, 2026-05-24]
hardware/Components/MBR2045CT/MBR2045CT.step
10.5 x 30.8 x 4.59 mm

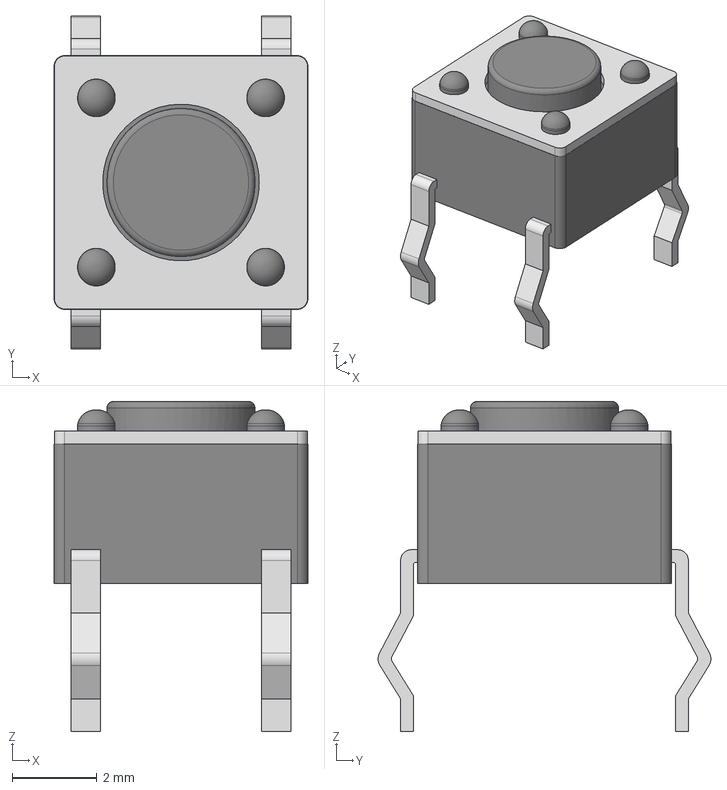
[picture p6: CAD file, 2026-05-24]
hardware/Components/MJTP1230/MJTP1230.stp
6.00 x 7.87 x 7.80 mm

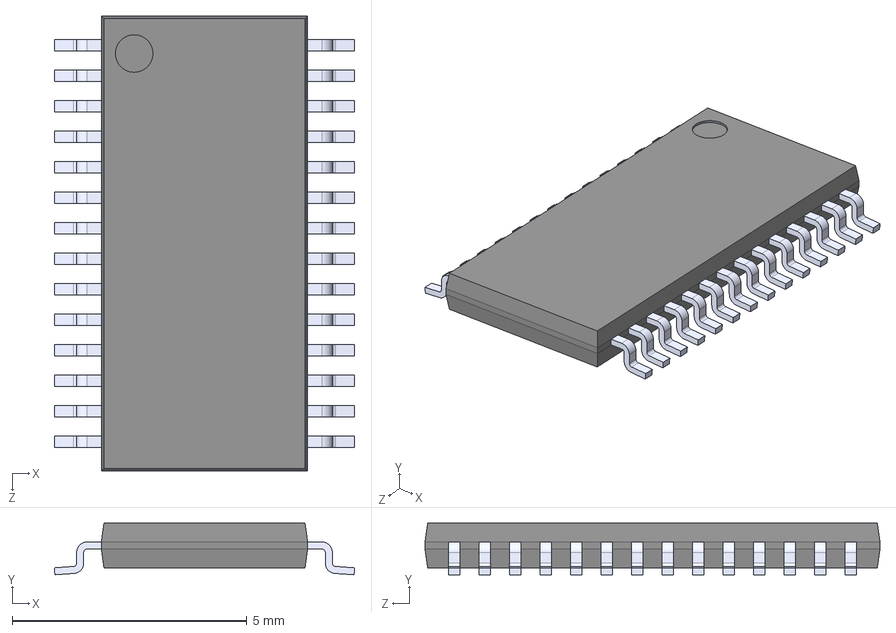
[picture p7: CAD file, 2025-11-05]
hardware/Components/PCA9685PW/PCA9685PW,118.STEP
6.40 x 1.10 x 9.70 mm

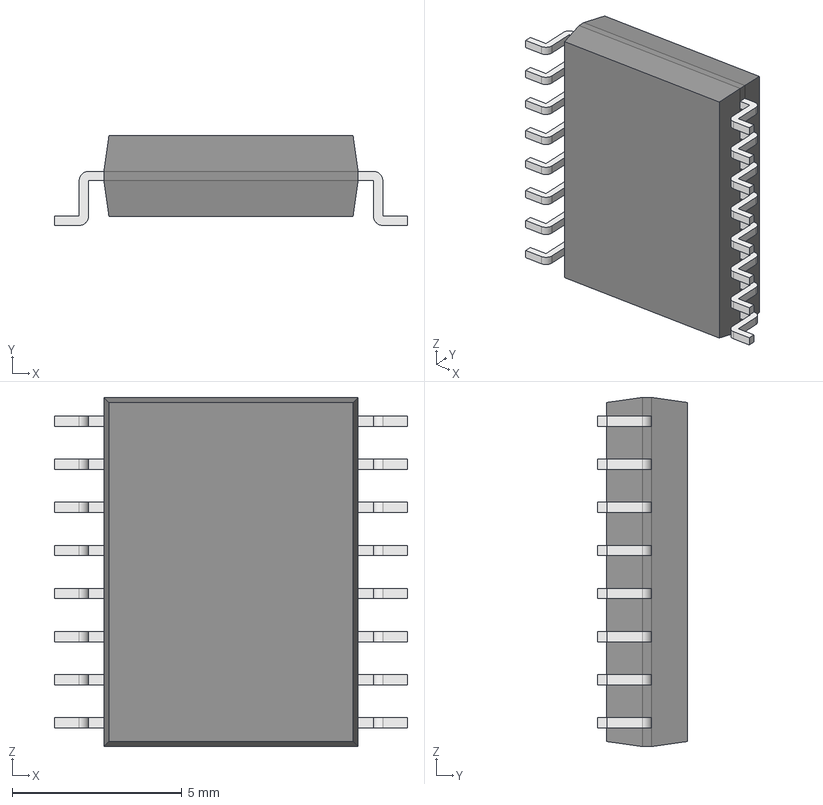
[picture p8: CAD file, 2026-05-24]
hardware/Components/PCF8574DW/PCF8574DW.step
10.4 x 2.65 x 10.3 mm
Body001 (Mirror #1) x 8
XY-plane x 12
X-axis x 12

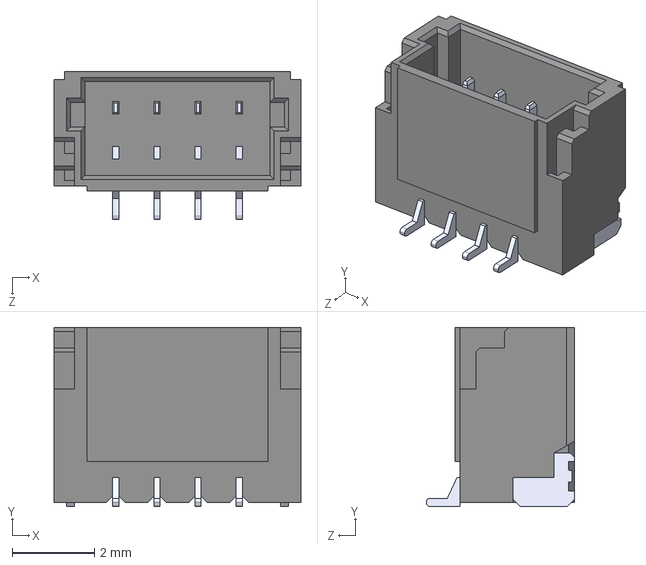
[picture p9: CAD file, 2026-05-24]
hardware/Components/QWIIC/4328.step
6.00 x 4.35 x 3.60 mm

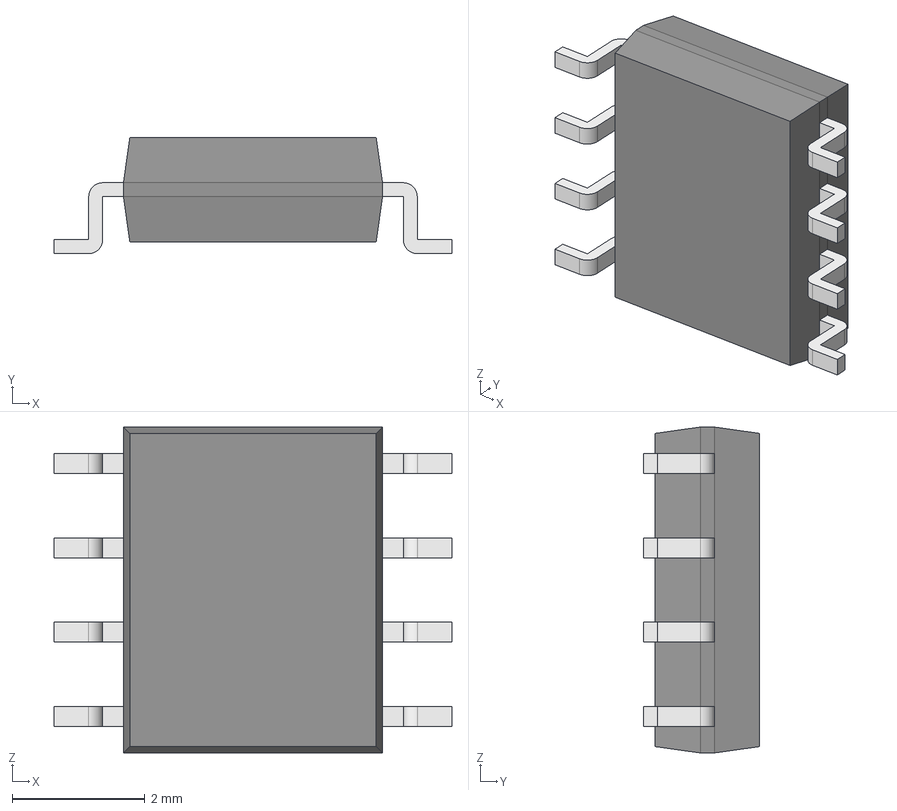
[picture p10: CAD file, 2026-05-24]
hardware/Components/SN65HVD230D/SN65HVD230D.step
5.99 x 1.75 x 4.91 mm
Body001 (Mirror #1) x 4
XY-plane x 12
X-axis x 12

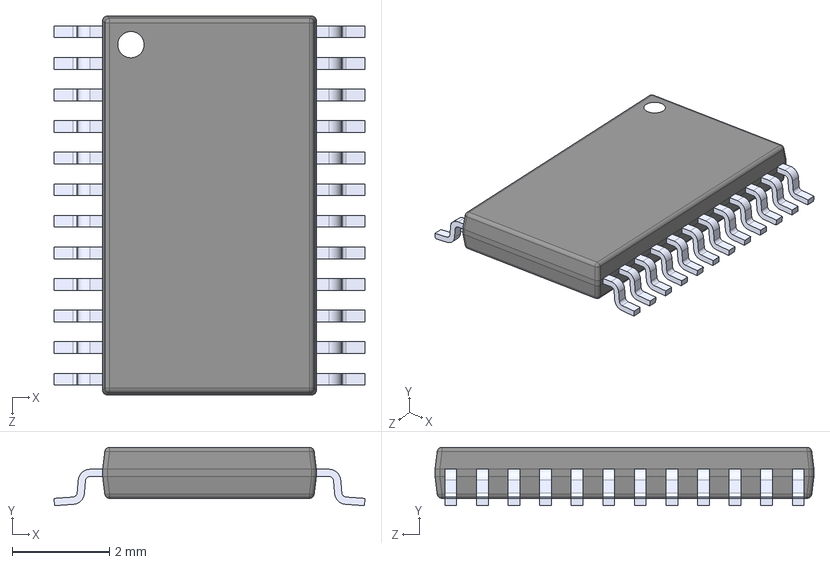
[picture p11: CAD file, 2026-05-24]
hardware/Components/TCA9548A/TCA9548APWR.step
6.40 x 1.20 x 7.80 mm

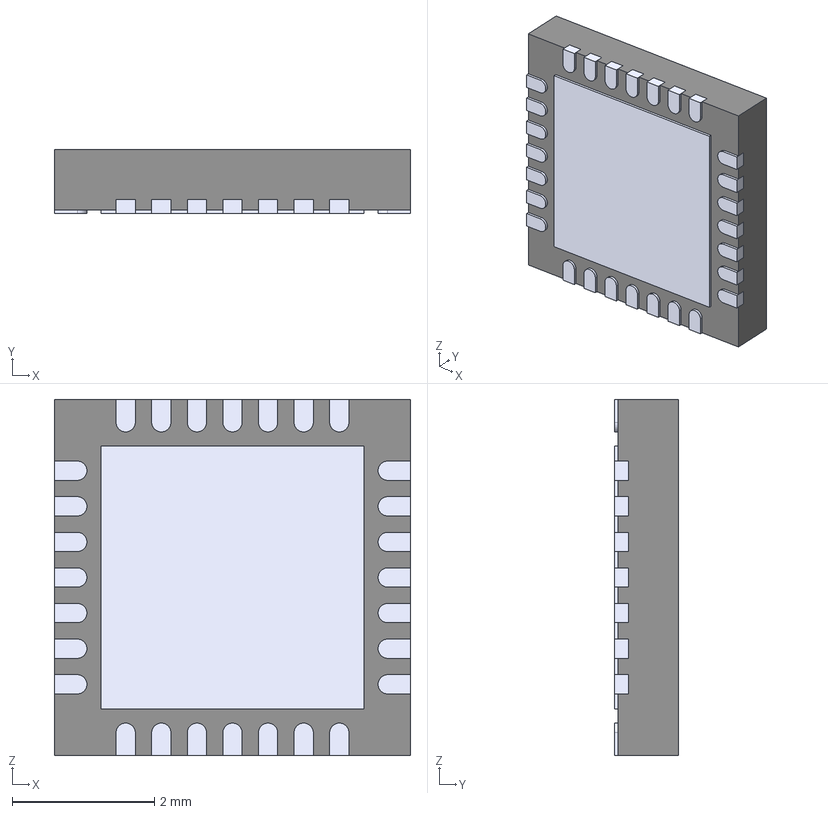
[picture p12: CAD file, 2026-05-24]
hardware/Components/TMC-2209-LA-T/TMC2209-LA-T.step
5.00 x 0.9 x 5.00 mm
Body_Solid1
Body001_Solid1
Array_Solid1 x 7
Array001_Solid2 x 6
Body002_Solid1
Array002_Solid1 x 7
Array003_Solid2 x 6
Body003_Solid1
Body004_Solid1

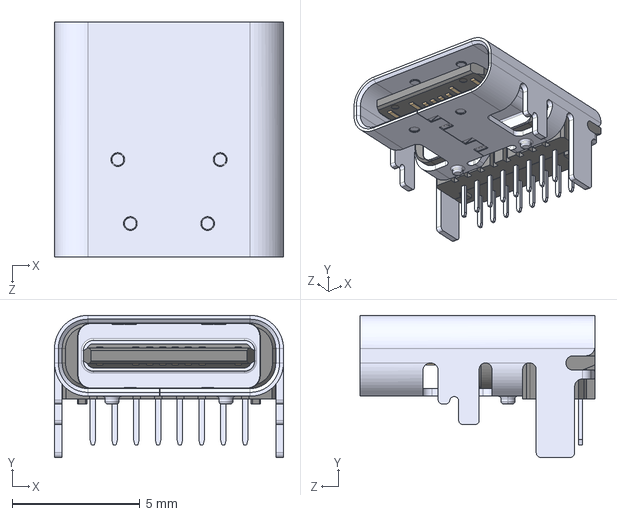
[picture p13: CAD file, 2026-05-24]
hardware/Components/USB4085GFA/USB4085-GF-A.step
8.95 x 5.56 x 9.17 mm

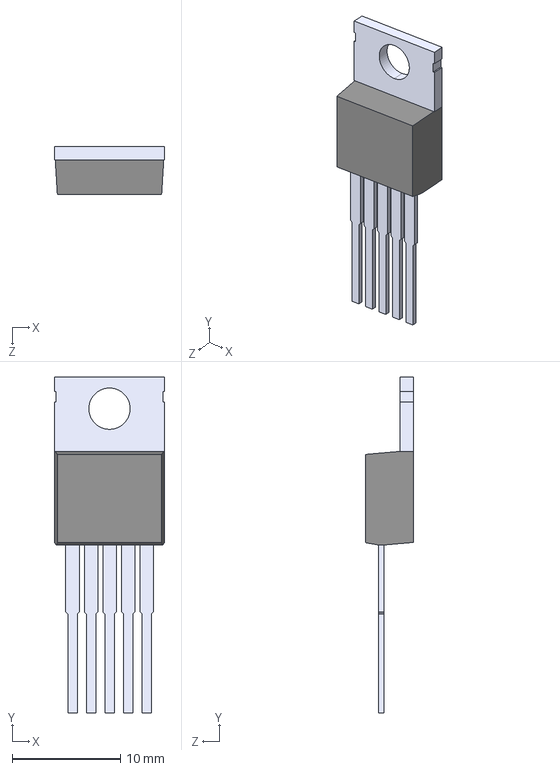
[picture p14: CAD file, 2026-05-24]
hardware/Components/XL4016/XL4016.step
10.2 x 31.0 x 4.45 mm

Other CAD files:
hardware/Components/XT60PW-M/XT60PW-M.step
hardware/Components/OS102011MS2QN1/OS102011MS2QN1.step

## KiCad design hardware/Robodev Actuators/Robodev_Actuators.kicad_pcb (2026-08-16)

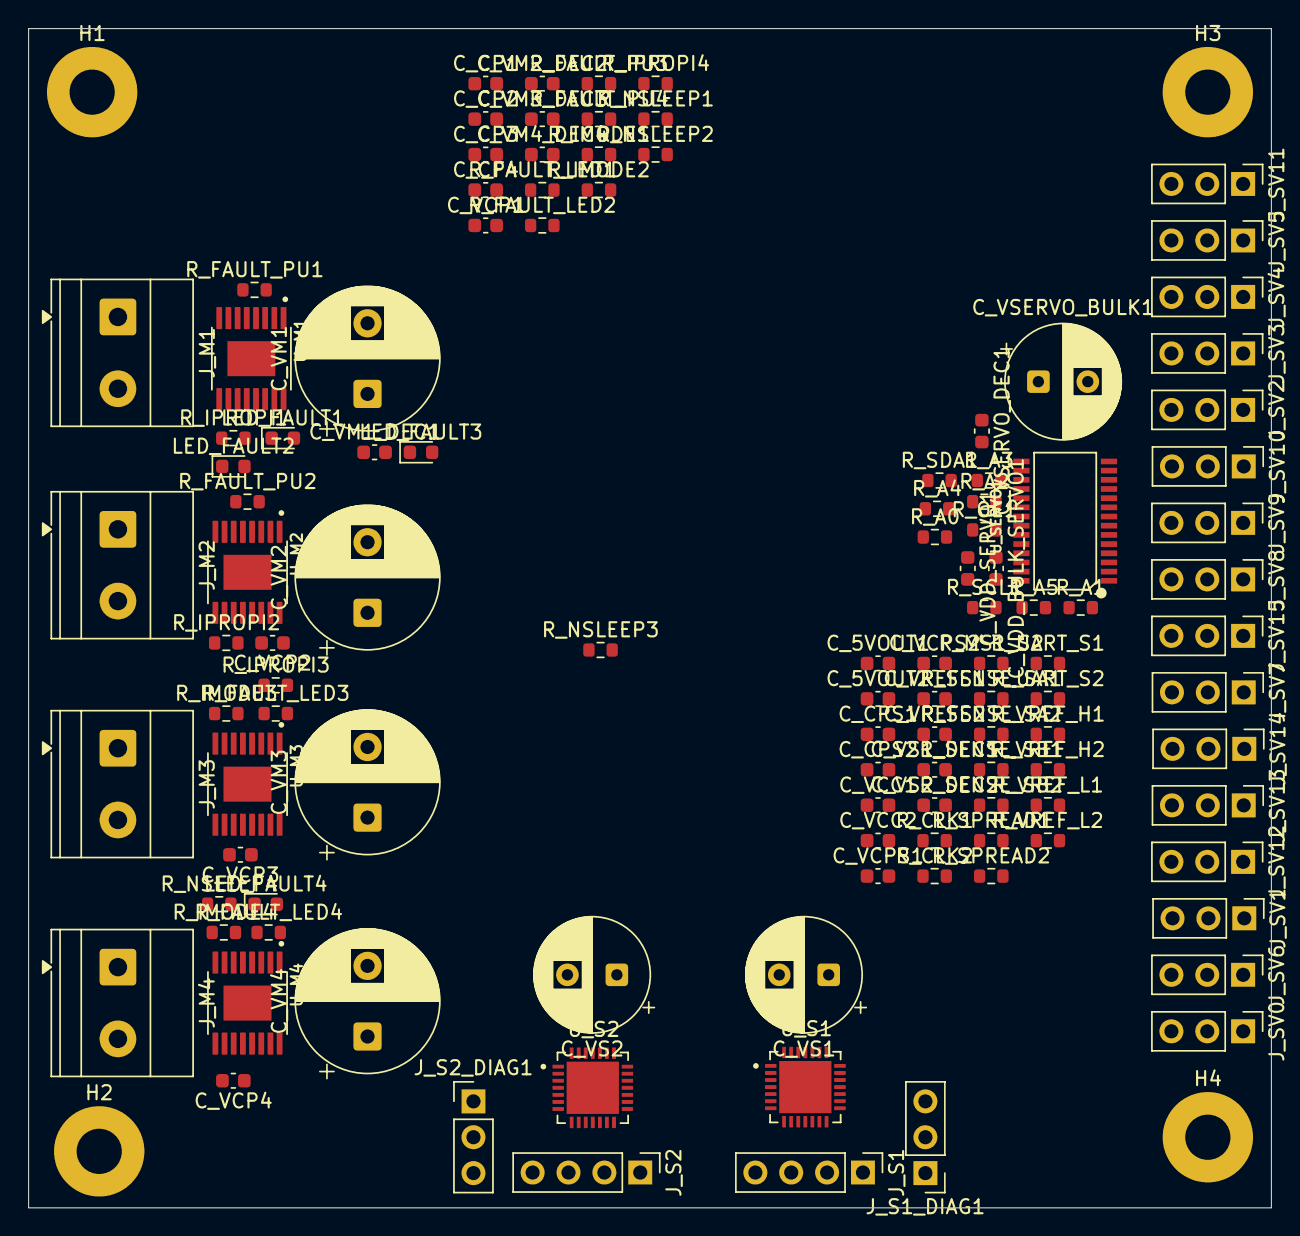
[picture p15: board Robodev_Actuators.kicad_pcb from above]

Board: 4 copper layers, 88.0 x 83.5 mm, 117 parts (0 on the bottom side), 107 nets, no tracks yet.

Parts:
C_5VOUT1, C_5VOUT2: 4.7 µF 10V X5R; C_0603_1608Metric
C_CP1: 22nF 50V X7R; C_0603_1608Metric
C_CP2, C_CP3, C_CP4: 22 nF 50V X7R; C_0603_1608Metric
C_CPS1, C_CPS2: 100 nF 50V X7R; C_0603_1608Metric
C_VCC1, C_VCC2: 100 nF 10V X7R; C_0603_1608Metric
C_VCP1, C_VCP2, C_VCP3, C_VCP4: 100 nF 50V X7R; C_0603_1608Metric
C_VCPS1, C_VCPS2: 100 nF 50V X7R; C_0603_1608Metric
C_VDD_BULK_SERVO1: 10 µF 10V X5R; C_0603_1608Metric
C_VDD_SERVO1: 100 nF 10V X7R; C_0603_1608Metric
C_VM1, C_VM2, C_VM3, C_VM4: 470 µF 50V electrolytic; CP_Radial_D10.0mm_P5.00mm
C_VM1_DEC1, C_VM2_DEC2, C_VM3_DEC3, C_VM4_DEC4: 100 nF 50V X7R; C_0603_1608Metric
C_VREFS1, C_VREFS2: 100 nF 10V X7R; C_0603_1608Metric
C_VS1, C_VS2: 100 µF 50V electrolytic; CP_Radial_D8.0mm_P3.50mm
C_VS1_DEC1, C_VS2_DEC2: 100 nF 50V X7R; C_0603_1608Metric
C_VSERVO_BULK1: 220 µF 25V electrolytic; CP_Radial_D8.0mm_P3.50mm
C_VSERVO_DEC1: 100 nF 50V X7R; C_0603_1608Metric
H1, H2, H3, H4: MountingHole_Pad; MountingHole_3.2mm_M3_Pad
J_M1, J_M2, J_M3, J_M4: Conn_01x02; TerminalBlock_Phoenix_MKDS-1,5-2-5.08_1x02_P5.08mm_Horizont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
J_S1, J_S2: Stepper 4-pin 2.54mm; PinHeader_1x04_P2.54mm_Vertical
J_S1_DIAG1: Stepper 1 DIAG/INDEX; PinHeader_1x03_P2.54mm_Vertical
J_S2_DIAG1: Stepper 2 DIAG/INDEX; PinHeader_1x03_P2.54mm_Vertical
J_SV0, J_SV1, J_SV2, J_SV3, J_SV4, J_SV5, J_SV6, J_SV7, J_SV8, J_SV9, J_SV10, J_SV11, J_SV12, J_SV13, J_SV14, J_SV15: Conn_01x03; PinHeader_1x03_P2.54mm_Vertical
LED_FAULT1, LED_FAULT2, LED_FAULT3, LED_FAULT4: LTST-C190KRKT Red; LED_0603_1608Metric
R_A0, R_A1, R_A2, R_A3, R_A4, R_A5: 100 kΩ 1% 0603; R_0603_1608Metric
R_CLK1, R_CLK2: 100 kΩ 1% 0603; R_0603_1608Metric
R_FAULT_LED1, R_FAULT_LED2, R_FAULT_LED3, R_FAULT_LED4: 1 kΩ 1% 0603; R_0603_1608Metric
R_FAULT_PU1, R_FAULT_PU2, R_FAULT_PU3, R_FAULT_PU4: 10 kΩ 1% 0603; R_0603_1608Metric
R_IMODE1, R_IMODE2, R_IMODE3, R_IMODE4: 20 kΩ 1% 0603; R_0603_1608Metric
R_IPROPI1, R_IPROPI2, R_IPROPI3, R_IPROPI4: 1 kΩ 1% 0603; R_0603_1608Metric
R_MS1_S2: 10 kΩ 1% 0603; R_0603_1608Metric
R_NSLEEP1, R_NSLEEP2, R_NSLEEP3, R_NSLEEP4: 100 kΩ 1% 0603; R_0603_1608Metric
R_OE1: 100 kΩ 1% 0603; R_0603_1608Metric
R_SCL1: 4.7 kΩ 1% 0603; R_0603_1608Metric
R_SDA1: 4.7 kΩ 1% 0603; R_0603_1608Metric
R_SENSE_SA1, R_SENSE_SA2: 100 mΩ 1% 0603; R_0603_1608Metric
R_SENSE_SB1, R_SENSE_SB2: 100 mΩ 1% 0603; R_0603_1608Metric
R_SPREAD1, R_SPREAD2: 100 kΩ 1% 0603; R_0603_1608Metric
R_UART_S1, R_UART_S2: 1 kΩ 1% 0603; R_0603_1608Metric
R_VREF_H1, R_VREF_H2: 10 kΩ 1% 0603; R_0603_1608Metric
R_VREF_L1, R_VREF_L2: 27 kΩ 1% 0603; R_0603_1608Metric
U_M1, U_M2, U_M3, U_M4: DRV8874PWPR; SOP65P640X120-17N
U_S1, U_S2: TMC2209-LA-T; QFN50P500X500X90-29N
U_SERVO1: PCA9685PW; TSSOP28-0.65-9.7X4.4MM

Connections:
+3V3: C_VCC1.2, C_VCC2.2, C_VDD_BULK_SERVO1.2, C_VDD_SERVO1.2, R_FAULT_PU1.1, R_FAULT_PU2.1, R_FAULT_PU3.1, R_FAULT_PU4.1, R_MS1_S2.1, R_NSLEEP1.1, R_NSLEEP2.1, R_NSLEEP3.1, R_NSLEEP4.1, R_SCL1.1, R_SDA1.1, R_VREF_H1.1, R_VREF_H2.1, U_M1.5 (VREF), U_M2.5 (VREF), U_M3.5 (VREF), U_M4.5 (VREF), U_S1.15 (VCC_IO), U_S2.15 (VCC_IO), U_SERVO1.28 (VDD)
/motor_dc/IPROPI_M1: R_IPROPI1.1, U_M1.6 (IPROPI)
/motor_dc/IPROPI_M2: R_IPROPI2.1, U_M2.6 (IPROPI)
/motor_dc/IPROPI_M3: R_IPROPI3.1, U_M3.6 (IPROPI)
/motor_dc/IPROPI_M4: R_IPROPI4.1, U_M4.6 (IPROPI)
/motor_dc/VMOT: C_VCP1.2, C_VCP2.2, C_VCP3.2, C_VCP4.2, C_VM1.1, C_VM1_DEC1.1, C_VM2.1, C_VM2_DEC2.1, C_VM3.1, C_VM3_DEC3.1, C_VM4.1, C_VM4_DEC4.1, U_M1.11 (VM), U_M2.11 (VM), U_M3.11 (VM), U_M4.11 (VM)
/motor_servo/I2C_SCL: R_SCL1.2, U_SERVO1.26 (SCL)
/motor_servo/I2C_SDA: R_SDA1.2, U_SERVO1.27 (SDA)
/motor_servo/SV_PWM0: J_SV0.3, U_SERVO1.6 (LED0)
/motor_servo/SV_PWM1: J_SV1.3, U_SERVO1.7 (LED1)
/motor_servo/SV_PWM2: J_SV2.3, U_SERVO1.8 (LED2)
/motor_servo/SV_PWM3: J_SV3.3, U_SERVO1.9 (LED3)
/motor_servo/SV_PWM4: J_SV4.3, U_SERVO1.10 (LED4)
/motor_servo/SV_PWM5: J_SV5.3, U_SERVO1.11 (LED5)
/motor_servo/SV_PWM6: J_SV6.3, U_SERVO1.12 (LED6)
/motor_servo/SV_PWM7: J_SV7.3, U_SERVO1.13 (LED7)
/motor_servo/SV_PWM8: J_SV8.3, U_SERVO1.15 (LED8)
/motor_servo/SV_PWM9: J_SV9.3, U_SERVO1.16 (LED9)
/motor_servo/SV_PWM10: J_SV10.3, U_SERVO1.17 (LED10)
/motor_servo/SV_PWM11: J_SV11.3, U_SERVO1.18 (LED11)
/motor_servo/SV_PWM12: J_SV12.3, U_SERVO1.19 (LED12)
/motor_servo/SV_PWM13: J_SV13.3, U_SERVO1.20 (LED13)
/motor_servo/SV_PWM14: J_SV14.3, U_SERVO1.21 (LED14)
/motor_servo/SV_PWM15: J_SV15.3, U_SERVO1.22 (LED15)
/motor_stepper/S1_VREF: C_VREFS1.1, R_VREF_H1.2, R_VREF_L1.1, U_S1.17 (VREF)
/motor_stepper/S2_VREF: C_VREFS2.1, R_VREF_H2.2, R_VREF_L2.1, U_S2.17 (VREF)
/motor_stepper/TMC_UART: R_UART_S1.1, R_UART_S2.1
GND: C_5VOUT1.2, C_5VOUT2.2, C_VCC1.1, C_VCC2.1, C_VDD_BULK_SERVO1.1, C_VDD_SERVO1.1, C_VM1.2, C_VM1_DEC1.2, C_VM2.2, C_VM2_DEC2.2, C_VM3.2, C_VM3_DEC3.2, C_VM4.2, C_VM4_DEC4.2, C_VREFS1.2, C_VREFS2.2, H1.1, H2.1, H3.1, H4.1, J_S1_DIAG1.1, J_S2_DIAG1.1, LED_FAULT1.1 (K), LED_FAULT2.1 (K), LED_FAULT3.1 (K), LED_FAULT4.1 (K), R_A0.1, R_A1.1, R_A2.1, R_A3.1, R_A4.1, R_A5.1, R_CLK1.1, R_CLK2.1, R_IMODE1.1, R_IMODE2.1, R_IMODE3.1, R_IMODE4.1, R_IPROPI1.2, R_IPROPI2.2, R_IPROPI3.2, R_IPROPI4.2, R_OE1.1, R_SPREAD1.1, R_SPREAD2.1, R_VREF_L1.2, R_VREF_L2.2, U_M1.16 (PMODE), U_M2.16 (PMODE), U_M3.16 (PMODE), U_M4.16 (PMODE), U_S1.9 (MS1_AD0), U_S1.10 (MS2_AD1), U_S2.10 (MS2_AD1), U_SERVO1.14 (VSS), U_SERVO1.25 (EXTCLK)
MGND: U_M1.9 (PGND), U_M1.15 (GND), U_M2.9 (PGND), U_M2.15 (GND), U_M3.9 (PGND), U_M3.15 (GND), U_M4.9 (PGND), U_M4.15 (GND)
unnamed: J_M1.1, U_M1.8 (OUT1)
unnamed: J_M1.2, U_M1.10 (OUT2)
unnamed: J_M2.1, U_M2.8 (OUT1)
unnamed: J_M2.2, U_M2.10 (OUT2)
unnamed: J_M3.1, U_M3.8 (OUT1)
unnamed: J_M3.2, U_M3.10 (OUT2)
unnamed: J_M4.1, U_M4.8 (OUT1)
unnamed: J_M4.2, U_M4.10 (OUT2)
unnamed: J_S1.1, U_S1.24 (OA1)
unnamed: J_S1.2, U_S1.21 (OA2)
unnamed: J_S1.3, U_S1.26 (OB1)
unnamed: J_S1.4, U_S1.1 (OB2)
unnamed: J_S1_DIAG1.2, U_S1.11 (DIAG)
unnamed: J_S1_DIAG1.3, U_S1.12 (INDEX)
unnamed: J_S2.1, U_S2.24 (OA1)
unnamed: J_S2.2, U_S2.21 (OA2)
unnamed: J_S2.3, U_S2.26 (OB1)
unnamed: J_S2.4, U_S2.1 (OB2)
unnamed: J_S2_DIAG1.2, U_S2.11 (DIAG)
unnamed: J_S2_DIAG1.3, U_S2.12 (INDEX)
unnamed: LED_FAULT1.2 (A), R_FAULT_LED1.2
unnamed: LED_FAULT2.2 (A), R_FAULT_LED2.2
unnamed: LED_FAULT3.2 (A), R_FAULT_LED3.2
unnamed: LED_FAULT4.2 (A), R_FAULT_LED4.2
unnamed: C_CP1.1, U_M1.13 (CPH)
unnamed: C_CP1.2, U_M1.14 (CPL)
unnamed: R_IMODE1.2, U_M1.7 (IMODE)
unnamed: R_FAULT_LED1.1, R_FAULT_PU1.2, U_M1.4 (NFAULT)
unnamed: R_NSLEEP1.2, U_M1.3 (NSLEEP)
unnamed: C_VCP1.1, U_M1.12 (VCP)
unnamed: C_CP2.1, U_M2.13 (CPH)
unnamed: C_CP2.2, U_M2.14 (CPL)
unnamed: R_IMODE2.2, U_M2.7 (IMODE)
unnamed: R_FAULT_LED2.1, R_FAULT_PU2.2, U_M2.4 (NFAULT)
unnamed: R_NSLEEP2.2, U_M2.3 (NSLEEP)
unnamed: C_VCP2.1, U_M2.12 (VCP)
unnamed: C_CP3.1, U_M3.13 (CPH)
unnamed: C_CP3.2, U_M3.14 (CPL)
unnamed: R_IMODE3.2, U_M3.7 (IMODE)
unnamed: R_FAULT_LED3.1, R_FAULT_PU3.2, U_M3.4 (NFAULT)
unnamed: R_NSLEEP3.2, U_M3.3 (NSLEEP)
unnamed: C_VCP3.1, U_M3.12 (VCP)
unnamed: C_CP4.1, U_M4.13 (CPH)
unnamed: C_CP4.2, U_M4.14 (CPL)
unnamed: R_IMODE4.2, U_M4.7 (IMODE)
unnamed: R_FAULT_LED4.1, R_FAULT_PU4.2, U_M4.4 (NFAULT)
unnamed: R_NSLEEP4.2, U_M4.3 (NSLEEP)
unnamed: C_VCP4.1, U_M4.12 (VCP)
unnamed: C_5VOUT1.1, U_S1.8 (5VOUT)
unnamed: R_SENSE_SA1.1, U_S1.23 (BRA)
unnamed: R_SENSE_SB1.1, U_S1.27 (BRB)
unnamed: R_CLK1.2, U_S1.13 (CLK)
unnamed: C_CPS1.1, U_S1.5 (CPI)
unnamed: C_CPS1.2, U_S1.4 (CPO)
unnamed: R_SPREAD1.2, U_S1.7 (SPREAD)
unnamed: C_VCPS1.1, U_S1.6 (VCP)
unnamed: R_UART_S1.2, U_S1.14 (~PD_UART)
unnamed: C_5VOUT2.1, U_S2.8 (5VOUT)
unnamed: R_SENSE_SA2.1, U_S2.23 (BRA)
unnamed: R_SENSE_SB2.1, U_S2.27 (BRB)
unnamed: R_CLK2.2, U_S2.13 (CLK)
unnamed: C_CPS2.1, U_S2.5 (CPI)
unnamed: C_CPS2.2, U_S2.4 (CPO)
unnamed: R_MS1_S2.2, U_S2.9 (MS1_AD0)
unnamed: R_SPREAD2.2, U_S2.7 (SPREAD)
unnamed: C_VCPS2.1, U_S2.6 (VCP)
unnamed: R_UART_S2.2, U_S2.14 (~PD_UART)
unnamed: R_A0.2, U_SERVO1.1 (A0)
unnamed: R_A1.2, U_SERVO1.2 (A1)
unnamed: R_A2.2, U_SERVO1.3 (A2)
unnamed: R_A3.2, U_SERVO1.4 (A3)
unnamed: R_A4.2, U_SERVO1.5 (A4)
unnamed: R_A5.2, U_SERVO1.24 (A5)
unnamed: R_OE1.2, U_SERVO1.23 (~OE)
SERVOGND: C_VSERVO_BULK1.2, C_VSERVO_DEC1.2, J_SV0.1, J_SV1.1, J_SV2.1, J_SV3.1, J_SV4.1, J_SV5.1, J_SV6.1, J_SV7.1, J_SV8.1, J_SV9.1, J_SV10.1, J_SV11.1, J_SV12.1, J_SV13.1, J_SV14.1, J_SV15.1
STEPGND: C_VCPS1.2, C_VCPS2.2, C_VS1.2, C_VS1_DEC1.1, C_VS2.2, C_VS2_DEC2.1, R_SENSE_SA1.2, R_SENSE_SA2.2, R_SENSE_SB1.2, R_SENSE_SB2.2, U_S1.3 (GND), U_S2.3 (GND)
VS: C_VS1.1, C_VS1_DEC1.2, C_VS2.1, C_VS2_DEC2.2, U_S1.22 (VS), U_S1.28 (VS), U_S2.22 (VS), U_S2.28 (VS)
VSERVO: C_VSERVO_BULK1.1, C_VSERVO_DEC1.1, J_SV0.2, J_SV1.2, J_SV2.2, J_SV3.2, J_SV4.2, J_SV5.2, J_SV6.2, J_SV7.2, J_SV8.2, J_SV9.2, J_SV10.2, J_SV11.2, J_SV12.2, J_SV13.2, J_SV14.2, J_SV15.2

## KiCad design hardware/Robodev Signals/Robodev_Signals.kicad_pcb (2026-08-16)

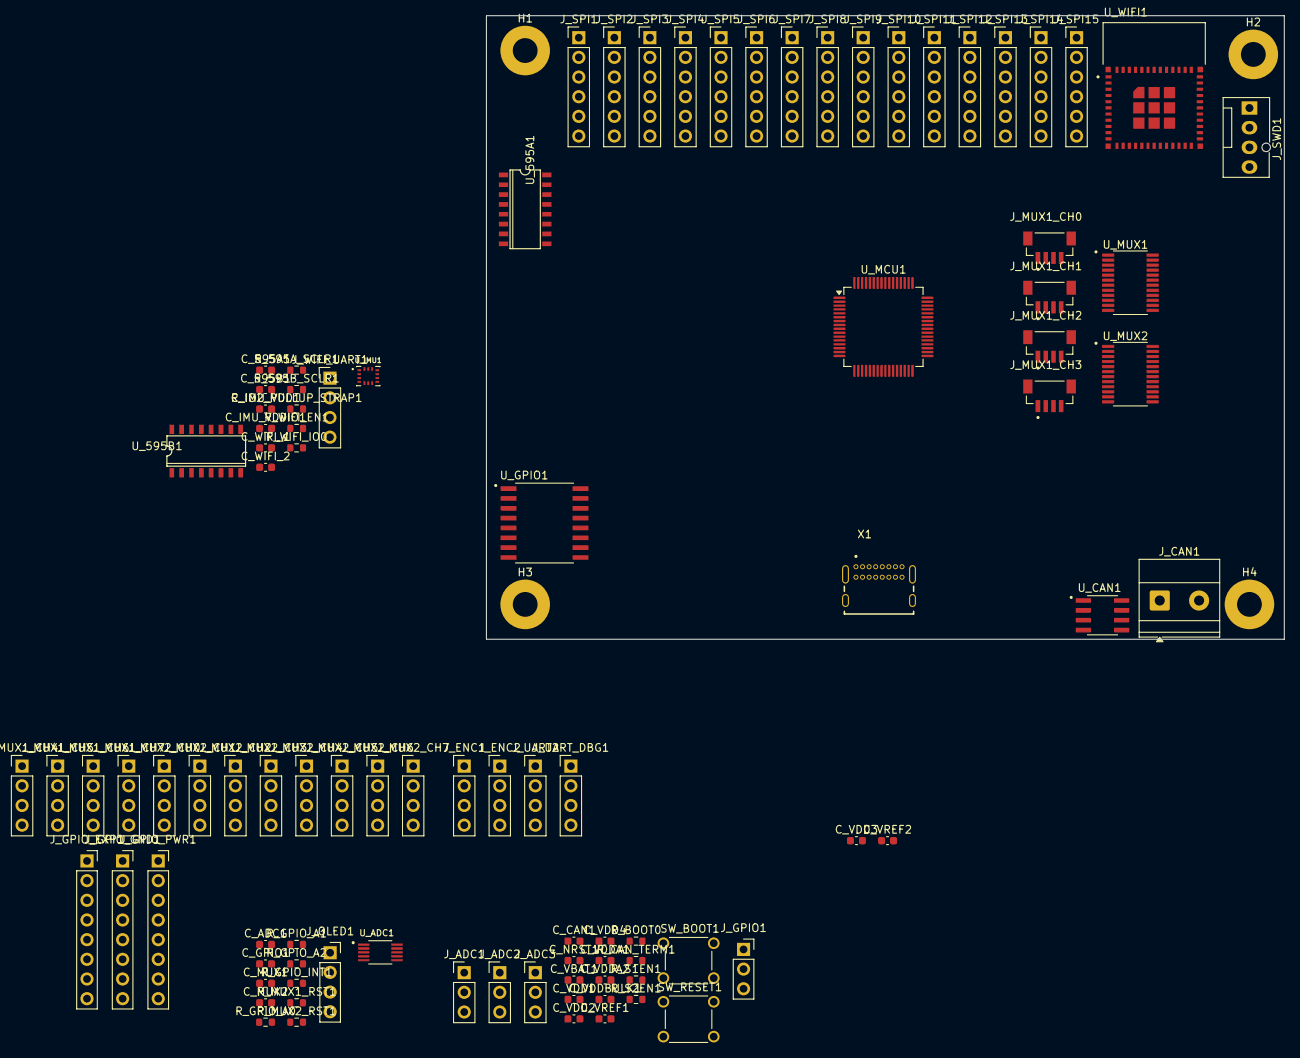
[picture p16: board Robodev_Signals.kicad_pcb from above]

Board: 4 copper layers, 103.0 x 80.5 mm, 100 parts (0 on the bottom side), 103 nets, no tracks yet.

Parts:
C_595A1, C_595B1: 100 nF 10V X7R; C_0603_1608Metric
C_ADC1: 100 nF 10V X7R; C_0603_1608Metric
C_CAN1: 100 nF 10V X7R; C_0603_1608Metric
C_GPIO1: 100 nF 10V X7R; C_0603_1608Metric
C_IMU_VDD1: 100 nF 10V X7R; C_0603_1608Metric
C_IMU_VDDIO1: 100 nF 10V X7R; C_0603_1608Metric
C_MUX1, C_MUX2: 100 nF 10V X7R; C_0603_1608Metric
C_NRST1: 100 nF 10V X7R; C_0603_1608Metric
C_VBAT1: 100 nF 10V X7R; C_0603_1608Metric
C_VDD1, C_VDD2, C_VDD3, C_VDD4: 100 nF 10V X7R; C_0603_1608Metric
C_VDDA1: 1 µF 10V X5R; C_0603_1608Metric
C_VDDA2: 10 nF 10V X7R; C_0603_1608Metric
C_VDDBULK1: 4.7 µF 10V X5R; C_0603_1608Metric
C_VREF1: 1 µF 10V X5R; C_0603_1608Metric
C_VREF2: 100 nF 10V X7R; C_0603_1608Metric
C_WIFI_1: 10 µF 10V X5R; C_0603_1608Metric
C_WIFI_2: 100 nF 10V X7R; C_0603_1608Metric
H1, H2, H3, H4: MountingHole_Pad; MountingHole_3.2mm_M3_Pad
J_ADC1, J_ADC2, J_ADC3: ADC Header 2.54mm; PinHeader_1x03_P2.54mm_Vertical
J_CAN1: CAN Bus 5.08mm; TerminalBlock_Phoenix_MKDS-1,5-2-5.08_1x02_P5.08mm_Horizont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
J_ENC1: Encoder 1 2.54mm; PinHeader_1x04_P2.54mm_Vertical
J_ENC2: Encoder 2 2.54mm; PinHeader_1x04_P2.54mm_Vertical
J_GPIO1: GPIO Header 2.54mm; PinSocket_1x03_P2.54mm_Vertical
J_GPIO_EXP1: Conn_01x08_F; PinSocket_1x08_P2.54mm_Vertical
J_GPIO_GND1: Conn_01x08F; PinSocket_1x08_P2.54mm_Vertical
J_GPIO_PWR1: Conn_01x08F; PinSocket_1x08_P2.54mm_Vertical
J_MUX1_CH0, J_MUX1_CH1, J_MUX1_CH2, J_MUX1_CH3: QWIIC I2C 2.54mm Header; ADAFRUIT_4328
J_MUX1_CH4, J_MUX1_CH5, J_MUX1_CH6, J_MUX1_CH7, J_MUX2_CH0, J_MUX2_CH1, J_MUX2_CH2, J_MUX2_CH3, J_MUX2_CH4, J_MUX2_CH5, J_MUX2_CH6, J_MUX2_CH7: I2C 2.54mm Header; PinHeader_1x04_P2.54mm_Vertical
J_OLED1: Conn_01x04; PinSocket_1x04_P2.54mm_Vertical
J_SPI1, J_SPI2, J_SPI3, J_SPI4, J_SPI5, J_SPI6, J_SPI7, J_SPI8, J_SPI9, J_SPI10, J_SPI11, J_SPI12, J_SPI13, J_SPI14, J_SPI15: SPI Expansion 2.54mm; PinHeader_1x06_P2.54mm_Vertical
J_SWD1: SWD Debug 2.54mm; FanPinHeader_1x04_P2.54mm_Vertical
J_UART2: UART General 2.54mm; PinHeader_1x04_P2.54mm_Vertical
J_UART_DBG1: UART Debug 2.54mm; PinHeader_1x04_P2.54mm_Vertical
J_WIFI_UART1: WiFi UART 2.54mm; PinHeader_1x04_P2.54mm_Vertical
R_595A_SCLR1, R_595B_SCLR1: 10 kΩ 1% 0603; R_0603_1608Metric
R_BOOT0: 10 kΩ 1% 0603; R_0603_1608Metric
R_CAN_TERM1: 120 Ω 1% 0603; R_0603_1608Metric
R_GPIO_A0, R_GPIO_A1, R_GPIO_A2: 100 kΩ 1% 0603; R_0603_1608Metric
R_GPIO_INT1: 10 kΩ 1% 0603; R_0603_1608Metric
R_IO2_PULLUP_STRAP1: 10 kΩ 1% 0603; R_0603_1608Metric
R_MUX1_RST1, R_MUX2_RST1: 10 kΩ 1% 0603; R_0603_1608Metric
R_S1EN1, R_S2EN1: 10 kΩ 1% 0603; R_0603_1608Metric
R_WIFI_EN1: 10 kΩ 1% 0603; R_0603_1608Metric
R_WIFI_IO0: 10 kΩ 1% 0603; R_0603_1608Metric
SW_BOOT1: MJTP1230; SW_MJTP1230
SW_RESET1: MJTP1230; SW_MJTP1230
U_595A1, U_595B1: 74HC595; SO16
U_ADC1: ADS1115IDGST; SOP50P490X110-10N
U_CAN1: SN65HVD230D; SOIC127P599X175-8N
U_GPIO1: PCF8574DW; SOIC127P1030X265-16N
U_IMU1: BMI270; XDCR_BMI270
U_MCU1: STM32G431RBTx; LQFP-64_10x10mm_P0.5mm
U_MUX1, U_MUX2: TCA9548APWR; SOP65P640X120-24N
U_WIFI1: ESP32-C3-MINI-1-N4; XCVR_ESP32-C3-MINI-1-N4
X1: USB4085-GF-A; GCT_USB4085-GF-A_REVB

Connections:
+3V3: C_595A1.2, C_595B1.2, C_ADC1.2, C_CAN1.2, C_GPIO1.2, C_IMU_VDD1.1, C_IMU_VDDIO1.2, C_MUX1.2, C_MUX2.2, C_VBAT1.2, C_VDD1.1, C_VDD2.1, C_VDD3.2, C_VDD4.1, C_VDDA1.2, C_VDDA2.2, C_VDDBULK1.2, C_VREF1.2, C_VREF2.2, C_WIFI_1.2, C_WIFI_2.2, J_ADC1.2, J_ADC2.2, J_ADC3.2, J_ENC1.2, J_ENC2.2, J_GPIO1.2, J_GPIO_PWR1.1, J_GPIO_PWR1.2, J_GPIO_PWR1.3, J_GPIO_PWR1.4, J_GPIO_PWR1.5, J_GPIO_PWR1.6, J_GPIO_PWR1.7, J_GPIO_PWR1.8, J_MUX1_CH0.2, J_MUX1_CH1.2, J_MUX1_CH2.2, J_MUX1_CH3.2, J_MUX1_CH4.2, J_MUX1_CH5.2, J_MUX1_CH6.2, J_MUX1_CH7.2, J_MUX2_CH0.2, J_MUX2_CH1.2, J_MUX2_CH2.2, J_MUX2_CH3.2, J_MUX2_CH4.2, J_MUX2_CH5.2, J_MUX2_CH6.2, J_MUX2_CH7.2, J_OLED1.1, J_SPI1.2, J_SPI2.2, J_SPI3.2, J_SPI4.2, J_SPI5.2, J_SPI6.2, J_SPI7.2, J_SPI8.2, J_SPI9.2, J_SPI10.2, J_SPI11.2, J_SPI12.2, J_SPI13.2, J_SPI14.2, J_SPI15.2, J_SWD1.1, J_UART2.2, J_UART_DBG1.2, J_WIFI_UART1.2, R_595A_SCLR1.1, R_595B_SCLR1.1, R_GPIO_INT1.1, R_IO2_PULLUP_STRAP1.1, R_MUX1_RST1.1, R_MUX2_RST1.1, R_S1EN1.1, R_S2EN1.1, R_WIFI_EN1.1, R_WIFI_IO0.1, SW_BOOT1.2_1, U_595A1.16 (VCC), U_595B1.16 (VCC), U_ADC1.8 (VDD), U_CAN1.3 (VCC), U_GPIO1.16 (VCC), U_IMU1.5 (VDDIO), U_IMU1.8 (VDD), U_MCU1.1 (VBAT), U_MCU1.16 (VDD), U_MCU1.28 (VREF+), U_MCU1.29 (VDDA), U_MCU1.32 (VDD), U_MCU1.48 (VDD), U_MCU1.64 (VDD), U_MUX1.24 (VCC), U_MUX2.1 (A0), U_MUX2.24 (VCC), U_WIFI1.3 (3V3)
/i2c_bus/GPIO_INT: R_GPIO_INT1.2, U_GPIO1.13 (~INT)
/i2c_bus/GPIO_P0: J_GPIO_EXP1.1, U_GPIO1.4 (P0)
/i2c_bus/GPIO_P1: J_GPIO_EXP1.2, U_GPIO1.5 (P1)
/i2c_bus/GPIO_P2: J_GPIO_EXP1.3, U_GPIO1.6 (P2)
/i2c_bus/GPIO_P3: J_GPIO_EXP1.4, U_GPIO1.7 (P3)
/i2c_bus/GPIO_P4: J_GPIO_EXP1.5, U_GPIO1.9 (P4)
/i2c_bus/GPIO_P5: J_GPIO_EXP1.6, U_GPIO1.10 (P5)
/i2c_bus/GPIO_P6: J_GPIO_EXP1.7, U_GPIO1.11 (P6)
/i2c_bus/GPIO_P7: J_GPIO_EXP1.8, U_GPIO1.12 (P7)
/i2c_bus/I2C_SCL: J_OLED1.3, U_ADC1.10 (SCL), U_GPIO1.14 (SCL), U_MUX1.22 (SCL), U_MUX2.22 (SCL)
/i2c_bus/I2C_SDA: J_OLED1.4, U_ADC1.9 (SDA), U_GPIO1.15 (SDA), U_MUX1.23 (SDA), U_MUX2.23 (SDA)
/i2c_bus/MUX1_SC0: J_MUX1_CH0.4, U_MUX1.5 (SC0)
/i2c_bus/MUX1_SC1: J_MUX1_CH1.4, U_MUX1.7 (SC1)
/i2c_bus/MUX1_SC2: J_MUX1_CH2.4, U_MUX1.9 (SC2)
/i2c_bus/MUX1_SC3: J_MUX1_CH3.4, U_MUX1.11 (SC3)
/i2c_bus/MUX1_SC4: J_MUX1_CH4.4, U_MUX1.14 (SC4)
/i2c_bus/MUX1_SC5: J_MUX1_CH5.4, U_MUX1.16 (SC5)
/i2c_bus/MUX1_SC6: J_MUX1_CH6.4, U_MUX1.18 (SC6)
/i2c_bus/MUX1_SC7: J_MUX1_CH7.4, U_MUX1.20 (SC7)
/i2c_bus/MUX1_SD0: J_MUX1_CH0.3, U_MUX1.4 (SD0)
/i2c_bus/MUX1_SD1: J_MUX1_CH1.3, U_MUX1.6 (SD1)
/i2c_bus/MUX1_SD2: J_MUX1_CH2.3, U_MUX1.8 (SD2)
/i2c_bus/MUX1_SD3: J_MUX1_CH3.3, U_MUX1.10 (SD3)
/i2c_bus/MUX1_SD4: J_MUX1_CH4.3, U_MUX1.13 (SD4)
/i2c_bus/MUX1_SD5: J_MUX1_CH5.3, U_MUX1.15 (SD5)
/i2c_bus/MUX1_SD6: J_MUX1_CH6.3, U_MUX1.17 (SD6)
/i2c_bus/MUX1_SD7: J_MUX1_CH7.3, U_MUX1.19 (SD7)
/i2c_bus/MUX2_SC0: J_MUX2_CH0.4, U_MUX2.5 (SC0)
/i2c_bus/MUX2_SC1: J_MUX2_CH1.4, U_MUX2.7 (SC1)
/i2c_bus/MUX2_SC2: J_MUX2_CH2.4, U_MUX2.9 (SC2)
/i2c_bus/MUX2_SC3: J_MUX2_CH3.4, U_MUX2.11 (SC3)
/i2c_bus/MUX2_SC4: J_MUX2_CH4.4, U_MUX2.14 (SC4)
/i2c_bus/MUX2_SC5: J_MUX2_CH5.4, U_MUX2.16 (SC5)
/i2c_bus/MUX2_SC6: J_MUX2_CH6.4, U_MUX2.18 (SC6)
/i2c_bus/MUX2_SC7: J_MUX2_CH7.4, U_MUX2.20 (SC7)
/i2c_bus/MUX2_SD0: J_MUX2_CH0.3, U_MUX2.4 (SD0)
/i2c_bus/MUX2_SD1: J_MUX2_CH1.3, U_MUX2.6 (SD1)
/i2c_bus/MUX2_SD2: J_MUX2_CH2.3, U_MUX2.8 (SD2)
/i2c_bus/MUX2_SD3: J_MUX2_CH3.3, U_MUX2.10 (SD3)
/i2c_bus/MUX2_SD4: J_MUX2_CH4.3, U_MUX2.13 (SD4)
/i2c_bus/MUX2_SD5: J_MUX2_CH5.3, U_MUX2.15 (SD5)
/i2c_bus/MUX2_SD6: J_MUX2_CH6.3, U_MUX2.17 (SD6)
/i2c_bus/MUX2_SD7: J_MUX2_CH7.3, U_MUX2.19 (SD7)
/spi_bus/SPI_CS0: U_595A1.15 (QA), U_IMU1.12 (CSB)
/spi_bus/SPI_CS1: J_SPI1.3, U_595A1.1 (QB)
/spi_bus/SPI_CS2: J_SPI2.3, U_595A1.2 (QC)
/spi_bus/SPI_CS3: J_SPI3.3, U_595A1.3 (QD)
/spi_bus/SPI_CS4: J_SPI4.3, U_595A1.4 (QE)
/spi_bus/SPI_CS5: J_SPI5.3, U_595A1.5 (QF)
/spi_bus/SPI_CS6: J_SPI6.3, U_595A1.6 (QG)
/spi_bus/SPI_CS7: J_SPI7.3, U_595A1.7 (QH)
/spi_bus/SPI_CS8: J_SPI8.3, U_595B1.15 (QA)
/spi_bus/SPI_CS9: J_SPI9.3, U_595B1.1 (QB)
/spi_bus/SPI_CS10: J_SPI10.3, U_595B1.2 (QC)
/spi_bus/SPI_CS11: J_SPI11.3, U_595B1.3 (QD)
/spi_bus/SPI_CS12: J_SPI12.3, U_595B1.4 (QE)
/spi_bus/SPI_CS13: J_SPI13.3, U_595B1.5 (QF)
/spi_bus/SPI_CS14: J_SPI14.3, U_595B1.6 (QG)
/spi_bus/SPI_CS15: J_SPI15.3, U_595B1.7 (QH)
/spi_bus/SPI_LATCH: U_595A1.12 (RCLK), U_595B1.12 (RCLK)
/spi_bus/SPI_MISO: J_SPI1.6, J_SPI2.6, J_SPI3.6, J_SPI4.6, J_SPI5.6, J_SPI6.6, J_SPI7.6, J_SPI8.6, J_SPI9.6, J_SPI10.6, J_SPI11.6, J_SPI12.6, J_SPI13.6, J_SPI14.6, J_SPI15.6, R_IO2_PULLUP_STRAP1.2, U_IMU1.1 (SDO), U_WIFI1.5 (IO2)
/spi_bus/SPI_MOSI: J_SPI1.5, J_SPI2.5, J_SPI3.5, J_SPI4.5, J_SPI5.5, J_SPI6.5, J_SPI7.5, J_SPI8.5, J_SPI9.5, J_SPI10.5, J_SPI11.5, J_SPI12.5, J_SPI13.5, J_SPI14.5, J_SPI15.5, U_595A1.14 (SER), U_IMU1.14 (SDX), U_WIFI1.21 (IO7)
/spi_bus/SPI_SCK: J_SPI1.4, J_SPI2.4, J_SPI3.4, J_SPI4.4, J_SPI5.4, J_SPI6.4, J_SPI7.4, J_SPI8.4, J_SPI9.4, J_SPI10.4, J_SPI11.4, J_SPI12.4, J_SPI13.4, J_SPI14.4, J_SPI15.4, U_595A1.11 (SCLK), U_595B1.11 (SCLK), U_IMU1.13 (SCX), U_WIFI1.20 (IO6)
/spi_bus/WIFI_RXD: J_WIFI_UART1.3, U_WIFI1.30 (RXD0)
/spi_bus/WIFI_TXD: J_WIFI_UART1.4, U_WIFI1.31 (TXD0)
/stm32/ADC_A1: J_ADC1.3, U_MCU1.34 (PB12)
/stm32/ADC_A2: J_ADC2.3, U_MCU1.36 (PB14)
/stm32/ADC_A3: J_ADC3.3, U_MCU1.37 (PB15)
/stm32/CAN_RX: R_BOOT0.1, SW_BOOT1.1_1, U_CAN1.4 (R), U_MCU1.61 (PB8)
/stm32/CAN_TX: U_CAN1.1 (D), U_MCU1.62 (PB9)
/stm32/ENC1_A: J_ENC1.3, U_MCU1.12 (PA0)
/stm32/ENC1_B: J_ENC1.4, U_MCU1.13 (PA1)
/stm32/ENC2_A: J_ENC2.3, U_MCU1.38 (PC6)
/stm32/ENC2_B: J_ENC2.4, U_MCU1.39 (PC7)
/stm32/GPIO_PC13: J_GPIO1.3, U_MCU1.2 (PC13)
/stm32/NRST: C_NRST1.2, SW_RESET1.1_2, U_MCU1.7 (PG10)
/stm32/S1_EN: R_S1EN1.2, U_MCU1.26 (PB2)
/stm32/S2_EN: R_S2EN1.2, U_MCU1.55 (PD2)
/stm32/SWCLK: J_SWD1.3, U_MCU1.50 (PA14)
/stm32/SWDIO: J_SWD1.2, U_MCU1.49 (PA13)
/stm32/UART2_RX: J_UART2.4, U_MCU1.33 (PB11)
/stm32/UART2_TX: J_UART2.3, U_MCU1.30 (PB10)
/stm32/UART_DBG_RX: J_UART_DBG1.4, U_MCU1.44 (PA10)
/stm32/UART_DBG_TX: J_UART_DBG1.3, U_MCU1.43 (PA9)
/stm32/UCPD_CC1: U_MCU1.59 (PB6), X1.A5 (CC1)
/stm32/UCPD_CC2: U_MCU1.57 (PB4), X1.B5 (CC2)
/stm32/USB_DM: U_MCU1.45 (PA11), X1.A7 (DN1), X1.B7 (DN2)
/stm32/USB_DP: U_MCU1.46 (PA12), X1.A6 (DP1), X1.B6 (DP2)
GND: C_595A1.1, C_595B1.1, C_ADC1.1, C_CAN1.1, C_GPIO1.1, C_IMU_VDD1.2, C_IMU_VDDIO1.1, C_MUX1.1, C_MUX2.1, C_NRST1.1, C_VBAT1.1, C_VDD1.2, C_VDD2.2, C_VDD3.1, C_VDD4.2, C_VDDA1.1, C_VDDA2.1, C_VDDBULK1.1, C_VREF1.1, C_VREF2.1, C_WIFI_1.1, C_WIFI_2.1, H1.1, H2.1, H3.1, H4.1, J_ADC1.1, J_ADC2.1, J_ADC3.1, J_ENC1.1, J_ENC2.1, J_GPIO1.1, J_GPIO_GND1.1, J_GPIO_GND1.2, J_GPIO_GND1.3, J_GPIO_GND1.4, J_GPIO_GND1.5, J_GPIO_GND1.6, J_GPIO_GND1.7, J_GPIO_GND1.8, J_MUX1_CH0.1, J_MUX1_CH1.1, J_MUX1_CH2.1, J_MUX1_CH3.1, J_MUX1_CH4.1, J_MUX1_CH5.1, J_MUX1_CH6.1, J_MUX1_CH7.1, J_MUX2_CH0.1, J_MUX2_CH1.1, J_MUX2_CH2.1, J_MUX2_CH3.1, J_MUX2_CH4.1, J_MUX2_CH5.1, J_MUX2_CH6.1, J_MUX2_CH7.1, J_OLED1.2, J_SPI1.1, J_SPI2.1, J_SPI3.1, J_SPI4.1, J_SPI5.1, J_SPI6.1, J_SPI7.1, J_SPI8.1, J_SPI9.1, J_SPI10.1, J_SPI11.1, J_SPI12.1, J_SPI13.1, J_SPI14.1, J_SPI15.1, J_SWD1.4, J_UART2.1, J_UART_DBG1.1, J_WIFI_UART1.1, R_BOOT0.2, R_GPIO_A0.1, R_GPIO_A1.1, R_GPIO_A2.1, SW_RESET1.2_2, U_595A1.8 (GND), U_595A1.13 (~OE), U_595B1.8 (GND), U_595B1.13 (~OE), U_ADC1.1 (ADDR), U_ADC1.3 (GND), U_CAN1.2 (GND), U_CAN1.8 (RS), U_GPIO1.8 (GND), U_IMU1.6 (GNDIO), U_IMU1.7 (GND), U_MCU1.15 (VSS), U_MCU1.27 (VSSA), U_MCU1.31 (VSS), U_MCU1.47 (VSS), U_MCU1.63 (VSS), U_MUX1.1 (A0), U_MUX1.2 (A1), U_MUX1.12 (GND), U_MUX1.21 (A2), U_MUX2.2 (A1), U_MUX2.12 (GND), U_MUX2.21 (A2), U_WIFI1.1 (GND), U_WIFI1.2 (GND), U_WIFI1.11 (GND), U_WIFI1.14 (GND), U_WIFI1.36 (GND), U_WIFI1.37 (GND), U_WIFI1.38 (GND), U_WIFI1.39 (GND), U_WIFI1.40 (GND), U_WIFI1.41 (GND), U_WIFI1.42 (GND), U_WIFI1.43 (GND), U_WIFI1.44 (GND), U_WIFI1.45 (GND), U_WIFI1.46 (GND), U_WIFI1.47 (GND), U_WIFI1.48 (GND), U_WIFI1.49_1 (GND), U_WIFI1.49_2 (GND), U_WIFI1.49_3 (GND), U_WIFI1.49_4 (GND), U_WIFI1.49_5 (GND), U_WIFI1.49_6 (GND), U_WIFI1.49_7 (GND), U_WIFI1.49_8 (GND), U_WIFI1.49_9 (GND), U_WIFI1.50 (GND), U_WIFI1.51 (GND), U_WIFI1.52 (GND), U_WIFI1.53 (GND), X1.A1 (GND), X1.A12 (GND), X1.B1 (GND), X1.B12 (GND), X1.S1 (SHELL), X1.S2 (SHELL), X1.S3 (SHELL), X1.S4 (SHELL)
unnamed: J_CAN1.1, R_CAN_TERM1.1, U_CAN1.7 (CANH)
unnamed: J_CAN1.2, R_CAN_TERM1.2, U_CAN1.6 (CANL)
unnamed: U_595A1.9 (QH'), U_595B1.14 (SER)
unnamed: R_595A_SCLR1.2, U_595A1.10 (~SCLR)
unnamed: R_595B_SCLR1.2, U_595B1.10 (~SCLR)
unnamed: R_GPIO_A0.2, U_GPIO1.1 (A0)
unnamed: R_GPIO_A1.2, U_GPIO1.2 (A1)
unnamed: R_GPIO_A2.2, U_GPIO1.3 (A2)
unnamed: R_MUX1_RST1.2, U_MUX1.3 (~RESET)
unnamed: R_MUX2_RST1.2, U_MUX2.3 (~RESET)
unnamed: R_WIFI_EN1.2, U_WIFI1.8 (EN)
unnamed: R_WIFI_IO0.2, U_WIFI1.12 (IO0)
VBUS: X1.A4 (VBUS), X1.A9 (VBUS), X1.B4 (VBUS), X1.B9 (VBUS)

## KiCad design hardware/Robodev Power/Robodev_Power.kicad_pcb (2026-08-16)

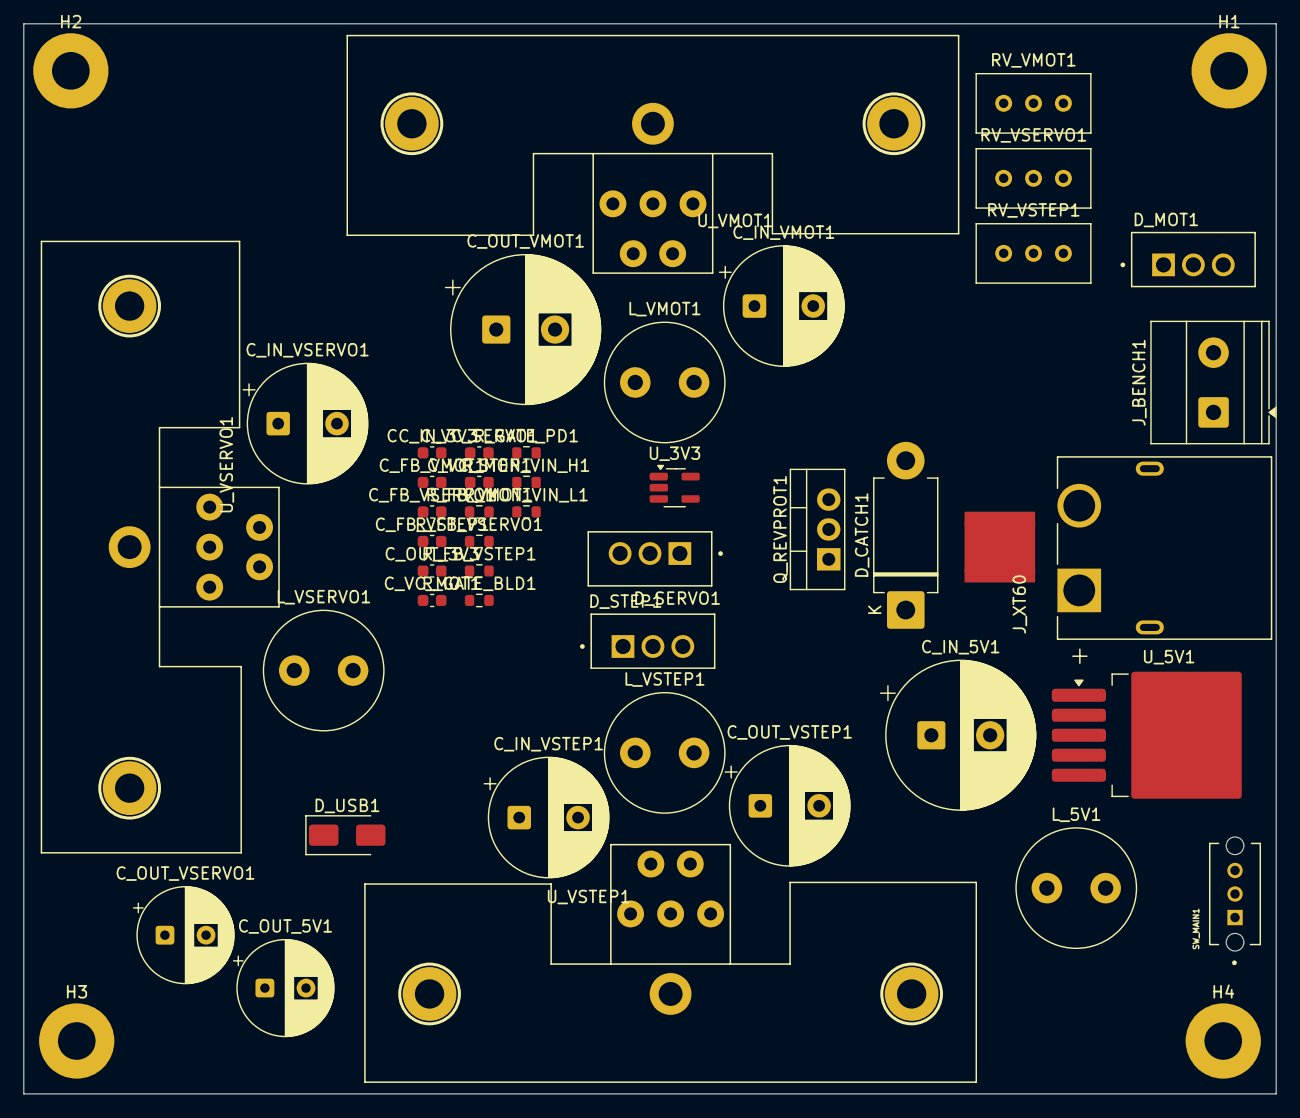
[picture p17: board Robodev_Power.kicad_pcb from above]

Board: 4 copper layers, 106.5 x 91.0 mm, 49 parts (0 on the bottom side), 24 nets, no tracks yet.

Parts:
CC_IN_3V3: 1 µF 10 V 0603; C_0603_1608Metric
C_FB_VMOT1: 33 nF 10 V 0603; C_0603_1608Metric
C_FB_VSERVO1: 33 nF 10 V 0603; C_0603_1608Metric
C_FB_VSTEP1: 33 nF 10 V 0603; C_0603_1608Metric
C_IN_5V1: 680 µF 50 V; CP_Radial_D12.5mm_P5.00mm
C_IN_VMOT1: 100 µF 50 V; CP_Radial_D10.0mm_P5.00mm
C_IN_VSERVO1: 100 µF 50 V; CP_Radial_D10.0mm_P5.00mm
C_IN_VSTEP1: 100 µF 50 V; CP_Radial_D10.0mm_P5.00mm
C_OUT_3V3: 1 µF 10 V 0603; C_0603_1608Metric
C_OUT_5V1: 220 µF 10 V; CP_Radial_D8.0mm_P3.50mm
C_OUT_VMOT1: 470 µF 50 V; CP_Radial_D12.5mm_P5.00mm
C_OUT_VSERVO1: 220 µF 25 V; CP_Radial_D8.0mm_P3.50mm
C_OUT_VSTEP1: 100 µF 50 V; CP_Radial_D10.0mm_P5.00mm
C_VC_MOT1: 1 µF ?V 0603; C_0603_1608Metric
C_VC_SERVO1: 1 µF ?V 0603; C_0603_1608Metric
C_VC_STEP1: 1 µF ?V 0603; C_0603_1608Metric
D_CATCH1: 1N5822; D_DO-201AD_P12.70mm_Horizontal
D_MOT1: MBR2045CT; TO254P1050X476X2020-3
D_SERVO1: MBR2045CT; TO254P1050X476X2020-3
D_STEP1: MBR2045CT; TO254P1050X476X2020-3
D_USB1: SS14; D_SMA
H1, H2, H3, H4: MountingHole_Pad; MountingHole_3.2mm_M3_Pad
J_BENCH1: Phoenix MKDS 1.5/2; TerminalBlock_Phoenix_MKDS-1,5-2-5.08_1x02_P5.08mm_Horizont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
J_XT60: XT60PW-M; AMASS_XT60PW-M
L_5V1: 33 µH 4 A; L_Radial_D10.0mm_P5.00mm_Fastron_07M
L_VMOT1: 47 µH 12 A; L_Radial_D10.0mm_P5.00mm_Fastron_07M
L_VSERVO1: 47 µH 12 A; L_Radial_D10.0mm_P5.00mm_Fastron_07M
L_VSTEP1: 47 µH 12 A; L_Radial_D10.0mm_P5.00mm_Fastron_07M
NT1: NetTie_4_Cross; NetTie-4_SMD_Pad2.0mm
Q_REVPROT1: IRF4905; TO-220-3_Vertical
RV_VMOT1: Bourns 3296W 10 kΩ; Potentiometer_Bourns_3296W_Vertical
RV_VSERVO1: Bourns 3296W 10 kΩ; Potentiometer_Bourns_3296W_Vertical
RV_VSTEP1: Bourns 3296W 10 kΩ; Potentiometer_Bourns_3296W_Vertical
R_FB_VMOT1: 100 kΩ 1% 0603; R_0603_1608Metric
R_FB_VSERVO1: 100 kΩ 1% 0603; R_0603_1608Metric
R_FB_VSTEP1: 100 kΩ 1% 0603; R_0603_1608Metric
R_GATE_BLD1: 100 kΩ 1% 0603; R_0603_1608Metric
R_GATE_PD1: 10 kΩ 1% 0603; R_0603_1608Metric
R_MON_VIN_H1: 100 kΩ 1% 0603; R_0603_1608Metric
R_MON_VIN_L1: 10 kΩ 1% 0603; R_0603_1608Metric
SW_MAIN1: OS102011MS2QN1; SW_OS102011MS2QN1
U_3V3: AP2112K-3.3; SOT-23-5_HandSoldering
U_5V1: LM2596HV-5.0; TO-263-5_TabPin3
U_VMOT1: XL4016; LM2576T2
U_VSERVO1: XL4016; LM2576T2
U_VSTEP1: XL4016; LM2576T2

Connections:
+3V3: C_OUT_3V3.1, U_3V3.5 (VOUT)
+5V: CC_IN_3V3.1, C_OUT_5V1.1, D_USB1.1 (K), L_5V1.1, U_3V3.1 (VIN), U_3V3.3 (EN), U_5V1.4 (FB)
/power/ADC_VIN: R_MON_VIN_H1.2, R_MON_VIN_L1.1
/power/VIN: J_BENCH1.1, J_XT60.1, Q_REVPROT1.2 (S), R_GATE_BLD1.1, R_MON_VIN_H1.1
/power/VIN_SWITCHED: C_IN_5V1.1, C_IN_VMOT1.1, C_IN_VSERVO1.1, C_IN_VSTEP1.1, C_VC_MOT1.1, C_VC_SERVO1.1, C_VC_STEP1.1, Q_REVPROT1.3 (D), U_5V1.1 (VIN), U_VMOT1.5 (VIN), U_VSERVO1.5 (VIN), U_VSTEP1.5 (VIN)
/power/VMOT: C_OUT_VMOT1.1, L_VMOT1.2, R_FB_VMOT1.1
/power/VSERVO: C_OUT_VSERVO1.1, L_VSERVO1.2, R_FB_VSERVO1.2
/power/VSTEP: C_OUT_VSTEP1.1, L_VSTEP1.1, R_FB_VSTEP1.1
GND: CC_IN_3V3.2, C_IN_5V1.2, C_IN_VMOT1.2, C_IN_VSERVO1.2, C_IN_VSTEP1.2, C_OUT_3V3.2, C_OUT_5V1.2, D_CATCH1.2 (A), D_MOT1.1, D_MOT1.3, D_SERVO1.1, D_SERVO1.3, D_STEP1.1, D_STEP1.3, H1.1, H2.1, H3.1, H4.1, J_BENCH1.2, J_XT60.2 (N), NT1.3, RV_VMOT1.3, RV_VSERVO1.3, RV_VSTEP1.3, R_GATE_PD1.1, R_MON_VIN_L1.2, U_3V3.2 (GND), U_5V1.3 (GND), U_5V1.5 (~ON/OFF), U_VMOT1.1 (GND), U_VSERVO1.1 (GND), U_VSTEP1.1 (GND)
MGND: C_OUT_VMOT1.2, NT1.1
unnamed: D_CATCH1.1 (K), L_5V1.2, U_5V1.2 (OUT)
unnamed: Q_REVPROT1.1 (G), R_GATE_BLD1.2, SW_MAIN1.1
unnamed: R_GATE_PD1.2, SW_MAIN1.2
unnamed: C_FB_VMOT1.2, RV_VMOT1.2, R_FB_VMOT1.2, U_VMOT1.2 (FB)
unnamed: C_FB_VMOT1.1, D_MOT1.2, L_VMOT1.1, RV_VMOT1.1, U_VMOT1.3 (OUT)
unnamed: C_VC_MOT1.2, U_VMOT1.4 (VC)
unnamed: C_FB_VSERVO1.2, RV_VSERVO1.2, R_FB_VSERVO1.1, U_VSERVO1.2 (FB)
unnamed: C_FB_VSERVO1.1, D_SERVO1.2, L_VSERVO1.1, RV_VSERVO1.1, U_VSERVO1.3 (OUT)
unnamed: C_VC_SERVO1.2, U_VSERVO1.4 (VC)
unnamed: C_FB_VSTEP1.2, RV_VSTEP1.2, R_FB_VSTEP1.2, U_VSTEP1.2 (FB)
unnamed: C_FB_VSTEP1.1, D_STEP1.2, L_VSTEP1.2, RV_VSTEP1.1, U_VSTEP1.3 (OUT)
unnamed: C_VC_STEP1.2, U_VSTEP1.4 (VC)
SERVOGND: C_OUT_VSERVO1.2, NT1.4
STEPGND: C_OUT_VSTEP1.2, NT1.2

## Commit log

2025-10-23 Added PCB project files
    [Rob_Dev_Board.kicad_pcb, Rob_Dev_Board.kicad_sch]
2025-10-23 Added technical docs for ESP32-S3
2025-10-24 Added component files for ESP32 and DRV8245H motor driver
    [ESP32-S3-WROOM-1U-N8R8.step, Rob_Dev_Board.kicad_pcb, Rob_Dev_Board.kicad_sch]
2025-11-05 Changed components for ESP32 and motor driver to in stock options from supplier
    [ESP32-S3-WROOM-1U-N16R8.step, RXZ0016A.stp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]
2025-11-05 Added some more components to PCB design, added datasheet for possible BLDC motor driver
    [PCA9685PW_118.step, Rob_Dev_Board.kicad_pcb, Rob_Dev_Board.kicad_sch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]
2025-11-05 Changed structure of project to allow for BLDC drivers
    [BLDC_PCB.kicad_pcb, BLDC_PCB.kicad_sch, ESP32-S3-WROOM-1U-N16R8.step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]
2025-11-06 Added acceler. and connector type to part library
    [BLDC_PCB.kicad_pcb, BLDC_PCB.kicad_sch, MPU-6050.step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]
2025-11-27 more testing
    [Rob_Dev_Board.kicad_pcb]
2025-11-27 testing more
    [Rob_Dev_Board.kicad_pcb]
2026-04-04 First major progress made towards planning. Pin layout drafted, no power systems yet.
    [BLDC_PCB.kicad_pcb, BLDC_PCB.kicad_sch, ESP32-S3-WROOM-1U-N16R8.step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]
2026-05-24 Substantial changes made - See readme for current running status
    [4328.step, 74HC595.step, ADS1115IDGST.step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]
2026-05-24 Removed artifacts of kicad and updated contributing.md
2026-08-16 Changed architecture of solutoion to stacked board architecture
    [Robodev.kicad_pcb, Robodev.kicad_sch, Robodev_Actuators.kicad_pcb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]
